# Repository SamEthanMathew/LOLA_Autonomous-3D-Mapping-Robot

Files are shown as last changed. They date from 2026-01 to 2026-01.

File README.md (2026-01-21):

# LOLA - Autonomous 3D-Mapping Robot

**Built in one week for Build18 2026**





> We built an autonomous 3D-mapping robot in one week.  
> Not a simulation. Not a demo script.  
> A real rover that drives and reconstructs the room around it.

---

## Overview

**LOLA** is a $150 mecanum-drive RC rover running on a Raspberry Pi 4 that autonomously explores and reconstructs 3D environments. The system combines LiDAR-based SLAM with RGB-only 3D reconstruction to create detailed spatial maps, all without relying on expensive depth cameras.

### Key Features

- ✅ **Real-time autonomous navigation** using LiDAR SLAM
- ✅ **3D reconstruction** from RGB video only (no depth camera needed)
- ✅ **Point-to-Line ICP (PL-ICP)** for faster and more accurate SLAM convergence
- ✅ **Cost-effective** - total build cost under $150
- ✅ **Accessible workflow** - heavy compute offloaded to Google Colab
- ✅ **Open-source** - designed for easy replication

---

## Technical Approach

### Hardware
- **Platform**: Mecanum-drive RC rover chassis
- **Compute**: Raspberry Pi 4
- **Sensor**: RPLiDAR A1/A2 for SLAM
- **Camera**: Standard RGB camera for 3D reconstruction
- **Total Cost**: ~$150

## 3D Printing

We 3D-printed several custom mounts and structural parts for LOLA using:

- **Printer**: BambuLab X1
- **Material**: PLA filament
- **Supports**: Not required (all parts were designed to print cleanly without supports)

These printed components helped with sensor mounting and securing electronics to the chassis.

## Software Architecture

```
┌─────────────────────────────────────┐
│         Raspberry Pi 4              │
│  • Motor Control                    │
│  • LiDAR SLAM (PL-ICP)              │
│  • Path Planning (RRT)              │
│  • Autonomous Navigation            │
└──────────────┬──────────────────────┘
               │
               │ Video Stream / Map Data
               ▼
┌─────────────────────────────────────┐
│    Offboard Compute (Colab/Laptop)  │
│  • CUT3R 3D Reconstruction          │
│  • Point Cloud Processing           │
└─────────────────────────────────────┘
```

### SLAM Pipeline

Our LiDAR-based SLAM implementation uses:

1. **Point-to-Line ICP (PL-ICP)** instead of traditional point-to-point ICP
   - Faster convergence
   - More accurate pose estimation
   - Better handling of sparse scan data

2. **SVD-based closed-form solve** for transformation estimation
   - Efficient computation
   - Numerically stable

3. **KD-tree for nearest-neighbor matching**
   - O(log n) query time
   - Efficient scan alignment

4. **Occupancy grid mapping** with dynamic updates
   - Real-time map visualization
   - Export to PNG for path planning

### Path Planning + Navigation

After SLAM generates an occupancy grid, LOLA plans motion through the environment using a lightweight **sampling-based path planner**.

****Pipeline:****
1. **Export occupancy grid** from SLAM (`map_exports/`)
2. Run `path_planner.py` to generate a **collision-free path** using **RRT (Rapidly-exploring Random Tree)**
3. Output waypoints + visualization:
   - `path_outputs/path_coords_*.json` (waypoint list)
   - `path_outputs/path_map_*.png` (path overlay on map)
4. `example_use_path.py` loads the JSON waypoints and sends motor commands to follow the route autonomously

****Why RRT?****
RRT is fast, simple, and works well on occupancy grids where obstacles can be irregular. It lets us generate feasible paths quickly without needing heavy compute or complex global planning libraries — perfect for a Pi-based rover.

This planning system turns our SLAM map into **actionable navigation**, enabling LOLA to autonomously explore rooms rather than just map them.

### 3D Reconstruction

We use **CUT3R** (Camera-Unified Transformer for 3D Reconstruction):
- Reconstructs 3D scenes using **only RGB video** + camera intrinsics/extrinsics
- No expensive depth cameras or structured light sensors needed
- Modified pipeline for easy iteration and team accessibility
- Runs on Google Colab for reproducibility

---

## Repository Structure

```
Build18-Contribution/
├── LiDARSensor.py              # SLAM implementation (PL-ICP, mapping, visualization)
├── path_planner.py             # RRT-based path planning on occupancy grids
├── example_use_path.py         # Example script for autonomous navigation
├── Vidto3Dmodel_Reconstruction.ipynb  # CUT3R reconstruction notebook (Colab)
├── drive/
│   └── manual_motor_control.py # Motor control interface
├── map_exports/                # Generated SLAM maps
└── path_outputs/               # Planned paths (JSON + visualization)
```

---

## Bill of Materials (BOM)

> Note: This BOM does **not** include the Raspberry Pi 4 and miscellaneous wiring/fasteners, which were not included in cost.

| # | Item | Qty | Unit Cost (USD) | Total (USD) | Product Link |
|---:|---|---:|---:|---:|---|
| 1 | Motor Driver | 1 | 10.59 | 10.59 | [L298N Motor Driver](https://www.amazon.com/dp/B0C5JCF5RS?ref=ppx_yo2ov_dt_b_fed_asin_title) |
| 2 | Robot Car Chassis | 1 | 39.21 | 39.21 | [Mecanum Robot Chassis](https://www.seeedstudio.com/Robot-car-Kit-RC-Smart-Car-Chassis-p-4226.html) |
| 3 | LiDAR Sensor | 1 | 104.94 | 104.94 | [RPLIDAR A1M8](https://a.co/d/cjdxPnk) |
| 4 | USB Camera | 1 | ~ | ~ | Used a regular pc camera |
| 5 | Pi4 Power Supply | 1 | ~ | ~ | Used a power bank |
| 6 | 9V Battery | 2 | ~ | ~ | 9V Alkaline Batteries |
|  | **Total** |  |  | **154.74** |  |

## Installation & Setup

### On Raspberry Pi 4

1. **Clone the repository**
   ```bash
   git clone https://github.com/yourusername/lola-robot.git
   cd lola-robot/Build18-Contribution
   ```

2. **Install dependencies**
   ```bash
   pip install numpy scipy pygame opencv-python rplidar-roboticia numba
   ```

3. **Connect LiDAR sensor**
   - Plug RPLiDAR into USB port
   - Verify with `ls /dev/ttyUSB*`

### For 3D Reconstruction (Colab)

1. Open `Vidto3Dmodel_Reconstruction.ipynb` in Google Colab
2. Upload your RGB video from the rover
3. Follow the notebook steps to generate 3D point clouds

---

## Usage

### 1. Run SLAM and Generate Map

```bash
python LiDARSensor.py
```

This will:
- Initialize the LiDAR sensor
- Start real-time SLAM with visualization
- Save occupancy grid maps to `map_exports/`

**Controls** (during SLAM):
- `S` - Save current map
- `R` - Reset map
- `ESC` - Exit

### 2. Plan Exploration Path

```bash
python path_planner.py map_exports/slam_map_YYYYMMDD-HHMMSS.png
```

This generates:
- `path_outputs/path_coords_*.json` - Waypoint coordinates
- `path_outputs/path_map_*.png` - Visualization of planned path

### 3. Execute Autonomous Navigation

```bash
python example_use_path.py
```

Loads the planned path and sends motor commands to follow waypoints autonomously.

### 4. 3D Reconstruction (Offboard)

1. Record RGB video while rover explores
2. Upload to Colab
3. Run `Vidto3Dmodel_Reconstruction.ipynb`
4. Download the reconstructed 3D model

---

## Results

- **SLAM Performance**: Real-time mapping at 10Hz with consistent loop closure
- **Path Planning**: RRT generates collision-free paths in <2 seconds
- **3D Reconstruction**: High-quality depth visualization showing room structure, furniture, and wall details
- **Autonomy**: Successfully navigates rooms without human intervention

---

## Team

Built with ❤️ by:
- **[Sam](https://www.linkedin.com/in/sam-mathew-1a9778254/)**
- **[Darren](https://www.linkedin.com/in/darrpinto/)**
- **[Tanay](https://www.linkedin.com/in/tanay-mishra-a86b25274/)**
- **[Jayden](https://www.linkedin.com/in/jayden-chen-3038a22a7/)**
- **[Jintong](https://www.linkedin.com/in/jintong-wang-096645289/)**

---

## Acknowledgments

Huge thanks to:
- The **Build18** organizing team
- Carnegie Mellon **ECE Department**
- All mentors who guided us throughout the sprint
- Open-source projects: CUT3R, RPLiDAR drivers, NumPy, SciPy
---

## Citation

If you use CUT3R in your work, please cite:

```bibtex
@inproceedings{cut3r,
  author    = {Qianqian Wang* and Yifei Zhang* and Aleksander Holynski and Alexei A. Efros and Angjoo Kanazawa},
  title     = {Continuous 3D Perception Model with Persistent State},
  booktitle = {CVPR},
  year      = {2025}
}
```

## Demo
Check out our 3D model generation & SLAM Pipeline demo's work: [Demo](https://github.com/SamEthanMathew/LOLA_Autonomous-3D-Mapping-Robot/commits/v1.0)

## License

This project is open-source and available under the MIT License.

---

## References

- [CUT3R: Camera-Unified Transformer for 3D Reconstruction](https://github.com/nianticlabs/cutr)
- [Point-to-Line ICP](https://ieeexplore.ieee.org/document/6906555)
- [RPLiDAR Documentation](https://www.slamtec.com/en/Lidar/A1)

---

**Built for Build18 2026** - One week. One robot. Real results.

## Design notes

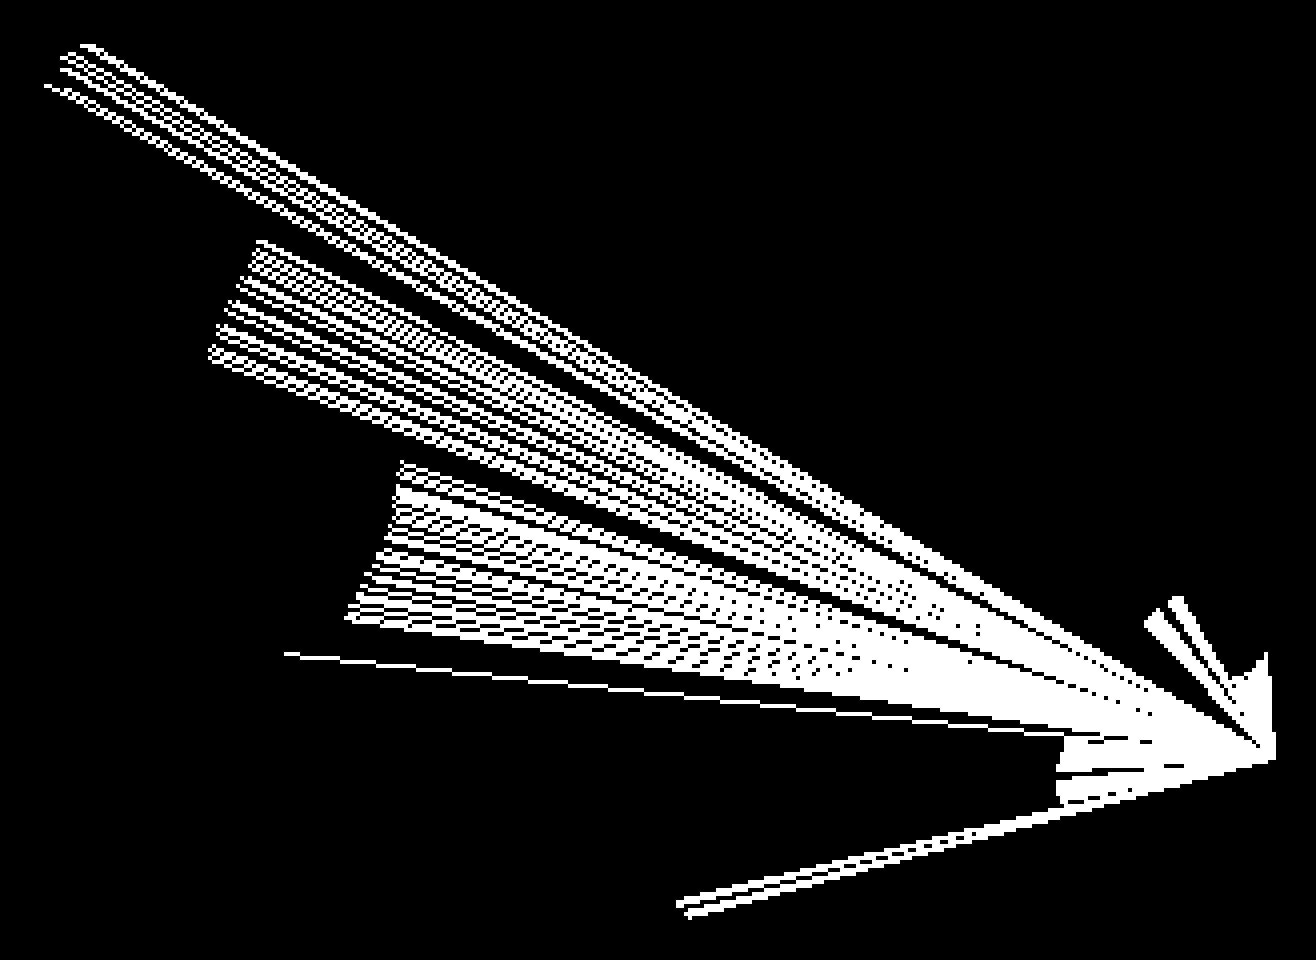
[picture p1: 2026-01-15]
map_exports/slam_map_20260114-220409.png

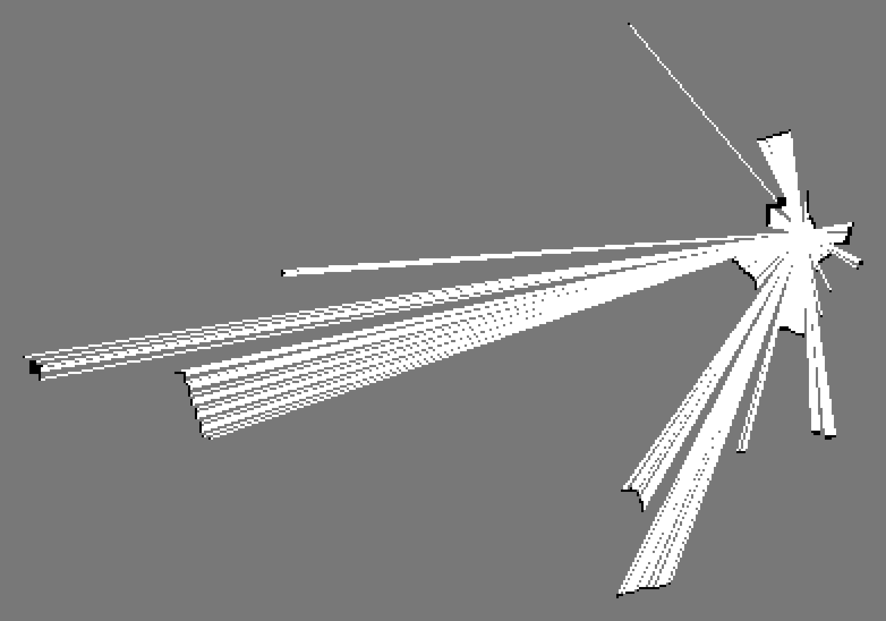
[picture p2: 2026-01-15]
map_exports/slam_map_20260114-215710.png

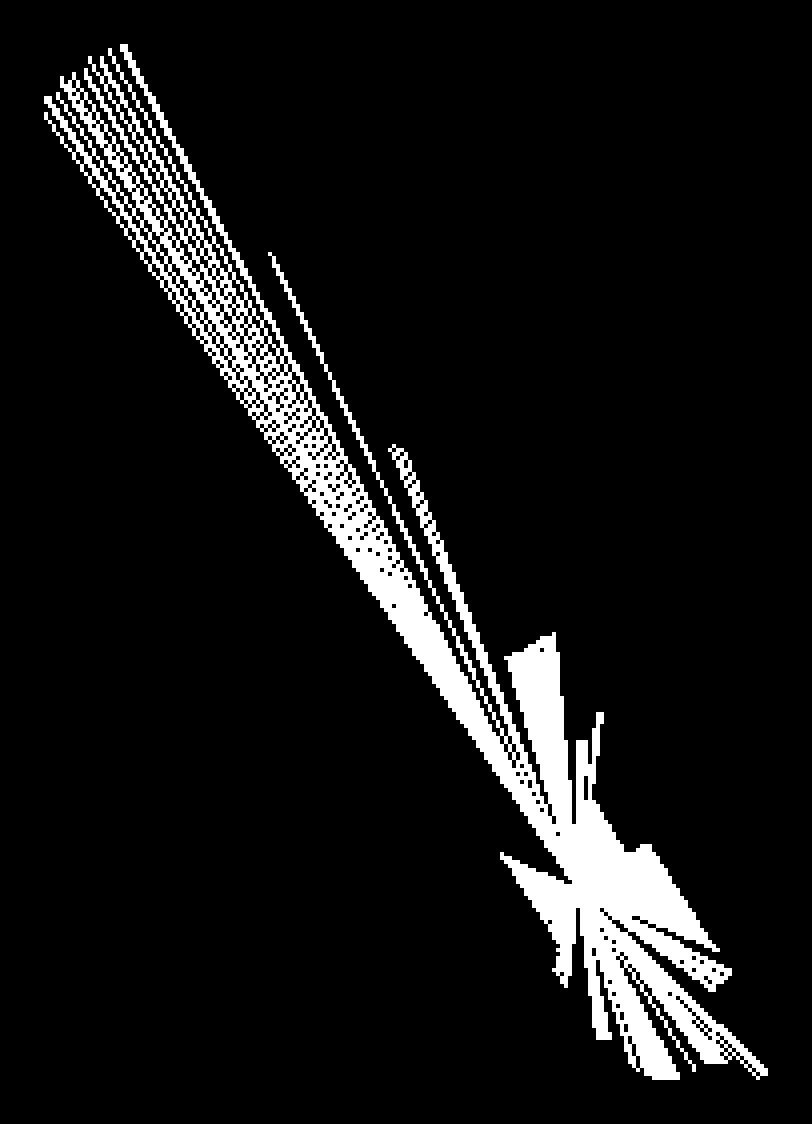
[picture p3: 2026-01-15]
map_exports/slam_map_20260114-220509.png

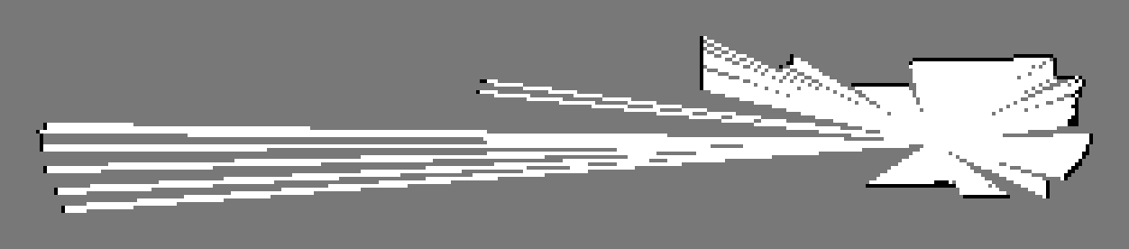
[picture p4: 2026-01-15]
map_exports/slam_map_20260114-220135.png

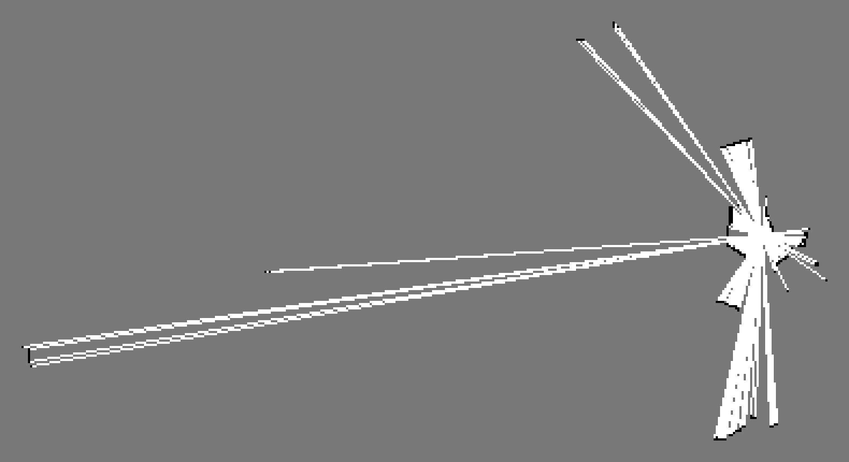
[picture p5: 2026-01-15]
map_exports/slam_map_20260114-215930.png

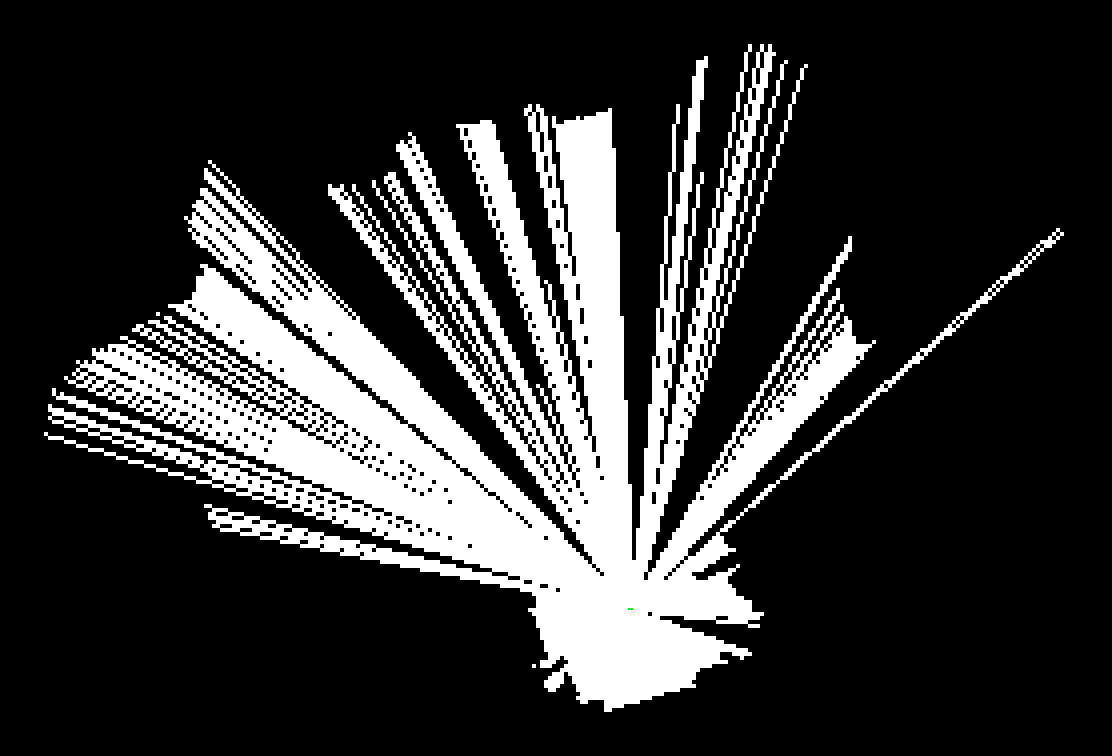
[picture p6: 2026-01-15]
map_exports/slam_map_20260114-220602.png

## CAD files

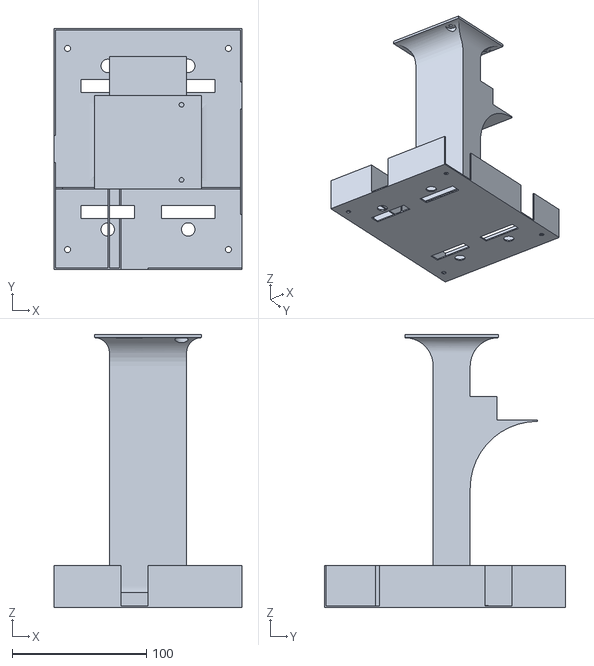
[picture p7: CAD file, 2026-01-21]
STL Files (3D prints)/chassis.STL
140.0 x 180.0 x 203.6

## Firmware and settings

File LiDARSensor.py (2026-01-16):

import threading
import json
from rplidar import RPLidar, RPLidarException
import time
import serial.tools.list_ports
import os
import pygame
import math
from collections import deque
import numpy as np
from scipy.spatial import KDTree
from scipy.ndimage import binary_closing
from scipy.spatial import KDTree
from scipy.ndimage import binary_closing
from numba import jit
import argparse

# --- SLAM Implementation ---
def best_fit_transform(A, B):
    '''
    Calculates the least-squares best-fit transform that maps corresponding points A to B in m spatial dimensions
    Input:
      A: Nxm numpy array of corresponding points
      B: Nxm numpy array of corresponding points
    Returns:
      T: (m+1)x(m+1) homogeneous transformation matrix
      R: mxm rotation matrix
      t: mx1 translation vector
    '''

    assert A.shape == B.shape

    # get number of dimensions
    m = A.shape[1]

    # translate points to their centroids
    centroid_A = np.mean(A, axis=0)
    centroid_B = np.mean(B, axis=0)
    AA = A - centroid_A
    BB = B - centroid_B

    # rotation matrix
    H = np.dot(AA.T, BB)
    U, S, Vt = np.linalg.svd(H)
    R = np.dot(Vt.T, U.T)

    # special reflection case
    if np.linalg.det(R) < 0:
       Vt[m-1,:] *= -1
       R = np.dot(Vt.T, U.T)

    # translation
    t = centroid_B.T - np.dot(R, centroid_A.T)

    # homogeneous transformation
    T = np.identity(m+1)
    T[:m, :m] = R
    T[:m, m] = t

    return T, R, t

@jit(nopython=True)
def bresenham_line(x0, y0, x1, y1):
    """
    Bresenham's Line Algorithm
    Returns a list of (x, y) tuples from (x0, y0) to (x1, y1)
    """
    points = []
    dx = abs(x1 - x0)
    dy = abs(y1 - y0)
    x, y = x0, y0
    sx = -1 if x0 > x1 else 1
    sy = -1 if y0 > y1 else 1
    
    if dx > dy:
        err = dx / 2.0
        while x != x1:
            points.append((x, y))
            err -= dy
            if err < 0:
                y += sy
                err += dx
            x += sx
    else:
        err = dy / 2.0
        while y != y1:
            points.append((x, y))
            err -= dx
            if err < 0:
                x += sx
                err += dy
            y += sy
    points.append((x, y))
    return points

def compute_normals(points, k=5):
    """
    Estimate normals for a 2D point cloud using k-nearest neighbors and PCA.
    Returns: N x 2 array of normal vectors.
    """
    if len(points) < k:
        return np.zeros((len(points), 2)) # Fallback
        
    tree = KDTree(points)
    normals = []
    
    # Query k neighbors for all points at once
    # k+1 because the point itself is included
    dists, indices = tree.query(points, k=k+1)
    
    for i, idxs in enumerate(indices):
        neighbors = points[idxs]
        # PCA
        mean = np.mean(neighbors, axis=0)
        centered = neighbors - mean
        cov = np.dot(centered.T, centered)
        values, vectors = np.linalg.eig(cov)
        
        # Normal is eigenvector corresponding to smallest eigenvalue
        min_idx = np.argmin(values)
        normal = vectors[:, min_idx]
        normals.append(normal)
        
    return np.array(normals)

def icp(A, B, init_pose=(0,0,0), max_iterations=20, tolerance=0.001):
    """
    The Iterative Closest Point method: aligns source A to target B
    Uses Point-to-Line metric via projected targets.
    """
    # Initial transform
    src = np.copy(A)
    
    # Pre-compute Target Info
    # 1. Build KD-Tree for B (Efficiency)
    target_tree = KDTree(B)
    
    # 2. Compute Normals for B (Point-to-Line)
    # Only if B has enough points
    use_plicp = len(B) > 10
    if use_plicp:
        B_normals = compute_normals(B, k=6)
    
    # Apply initial estimate
    theta = init_pose[2]
    c, s = math.cos(theta), math.sin(theta)
    R_init = np.array([[c, -s], [s, c]])
    src = np.dot(src, R_init.T)
    src += init_pose[:2]
    
    prev_error = 0
    total_T = np.identity(3)
    
    # Handle initial offset in matrix form
    T_init = np.identity(3)
    T_init[:2, :2] = R_init
    T_init[:2, 2] = init_pose[:2]
    total_T = np.dot(T_init, total_T)

    for i in range(max_iterations):
        # 1. Find correspondence
        # Query tree for all src points
        distances, indices = target_tree.query(src)
        
        target_points = B[indices]
        
        # 2. Optimize
        if use_plicp:
            # Point-to-Line Improvement:
            # Project src points onto the plane defined by (target_point, normal)
            # q_proj = p - dot(p - q, n) * n
            # But wait, we want to align 'src' to 'target line'.
            # We treat 'q_proj' as the point 'src' should try to reach to satisfy the planar constraint.
            
            normals = B_normals[indices]
            
            # Vector from point in B to point in A
            diff = src - target_points
            
            # Project this vector onto the normal
            # dot product row-wise
            dist_along_normal = np.sum(diff * normals, axis=1)
            
            # The target point on the "line" is src shifted back along the normal
            # dest = src - dist * normal
            # This works effectively as allowing sliding along the wall
            target_points_proj = src - (normals * dist_along_normal[:, np.newaxis])
            
            # Use these projected points as targets for standard SVD solver
            T, _, _ = best_fit_transform(src, target_points_proj)
        else:
             # Standard Point-to-Point
             T, _, _ = best_fit_transform(src, target_points)

        # 3. Update
        src_h = np.ones((src.shape[0], 3))
        src_h[:,:2] = src
        src_h = np.dot(T, src_h.T).T
        src = src_h[:,:2]

        total_T = np.dot(T, total_T)

        # Check error (Mean Distance)
        mean_error = np.mean(distances)
        if np.abs(prev_error - mean_error) < tolerance:
            break
        prev_error = mean_error

    return total_T, distances

class SimpleSLAM:
    def __init__(self):
        # PROBABILISTIC GRID MAP
        # Key: (int_x, int_y) tuple representing 30mm grid cells
        # Value: [sum_x, sum_y, count]
        self.global_grid = {} 
        self.GRID_RESOLUTION = 30 # mm
        
        self.pose = np.array([0.0, 0.0, 0.0]) # x, y, theta
        self.path = [] # History of poses
        
        self.scan_buffer = [] # Buffer to accumulate scans before SLAM update
        self.SCAN_BUFFER_SIZE = 4 # How many scans to merge (robustness)
        self.prev_dense_scan = None
        
    def process_scan(self, scan_points):
        """
        Accumulates scans to create a dense 'Keyframe'.
        Runs ICP only when buffer is full.
        """
        # 1. Convert to Cartesian (Robot Frame)
        current_scan = []
        for p in scan_points:
            if p.distance > 0:
                rad = math.radians(p.angle)
                x = p.distance * math.cos(rad)
                y = p.distance * math.sin(rad)
                current_scan.append([x, y])
        
        # Add to buffer
        if len(current_scan) > 10:
             self.scan_buffer.extend(current_scan)
             
        # Only process if buffer is full (Signal Integration)
        # We assume robot moves slowly enough that 4 scans (~0.5s) is "static" enough
        # or that the blur is acceptable for specific density.
        current_rev = scan_points[0].revolution if scan_points else 0
        
        # Check if we have enough data (using a simple counter or checking length)
        # Since process_scan is called once per revolution roughly
        # We need a counter in the class, or just check list length logic
        # But process_scan is called per frame? No, per revolution based on main loop.
        # So we just count calls?
        # Let's use the length of the buffer as a proxy? No, scans vary.
        # Let's add a counter.
        
        if not hasattr(self, 'buffer_count'):
             self.buffer_count = 0
        self.buffer_count += 1
        
        if self.buffer_count < self.SCAN_BUFFER_SIZE:
             return
             
        # --- PROCESS KEYFRAME ---
        self.buffer_count = 0
        if not self.scan_buffer:
             return
             
        dense_scan = np.array(self.scan_buffer)
        self.scan_buffer = [] # Clear for next batch
        
        # DOWNSAMPLE if too huge (ICP speed)
        # 4 scans * 200 pts = 800 pts. limit to 400 for speed?
        if len(dense_scan) > 400:
             indices = np.linspace(0, len(dense_scan)-1, 400, dtype=int)
             dense_scan_small = dense_scan[indices]
        else:
             dense_scan_small = dense_scan

        # 2. Estimate Motion (ICP)
        d_pose = np.identity(3)
        moved = False
        
        if self.prev_dense_scan is not None:
             try:
                 # Align current dense scan to previous dense scan
                 T, distances = icp(dense_scan_small, self.prev_dense_scan)
                 d_pose = T
                 
                 # Check Motion Thresholds (Keyframe Logic)
                 # prevents drift when static
                 dx = d_pose[0, 2]
                 dy = d_pose[1, 2]
                 dtheta = math.atan2(d_pose[1, 0], d_pose[0, 0])
                 
                 dist_moved = math.sqrt(dx*dx + dy*dy)
                 rot_moved = abs(math.degrees(dtheta))
                 
                 if dist_moved > 20 or rot_moved > 2.0: # 20mm or 2 degrees
                      moved = True
                 else:
                      # If motion is tiny, ignore it to prevent drift?
                      # Or accumulate it? safer to ignore for "rock solid" static map
                      d_pose = np.identity(3) # Force zero
                      # But we might still want to add points to map if new area seen?
                      # No, if we didn't move, we see same thing.
                      pass

             except Exception as e:
                 print(f"ICP Error: {e}")
                 pass
        else:
             moved = True # First frame always updates
        
        # Extract refined delta
        dx = d_pose[0, 2]
        dy = d_pose[1, 2]
        dtheta = math.atan2(d_pose[1, 0], d_pose[0, 0])
        
        # 3. Update Global Pose
        gx = dx * math.cos(self.pose[2]) - dy * math.sin(self.pose[2])
        gy = dx * math.sin(self.pose[2]) + dy * math.cos(self.pose[2])
        
        self.pose[0] += gx
        self.pose[1] += gy
        self.pose[2] += dtheta
        
        # 4. Update Map & Reference
        # If we moved (or it's the first frame), update the map
        if moved or self.prev_dense_scan is None:
             c, s = math.cos(self.pose[2]), math.sin(self.pose[2])
             R_global = np.array([[c, -s], [s, c]])
             
             # Transform dense scan to global
             global_points = np.dot(dense_scan, R_global.T) + self.pose[:2]
             
             # PROBABILISTIC UPDATE (RAYCASTING)
             # Update cells along the ray to be FREE
             # Update end point to be OCCUPIED
             
             # Convert robot pose to grid coords
             rob_ix = int(round(self.pose[0] / self.GRID_RESOLUTION))
             rob_iy = int(round(self.pose[1] / self.GRID_RESOLUTION))
             
             for p in global_points:
                 gx, gy = p[0], p[1]
                 ix = int(round(gx / self.GRID_RESOLUTION))
                 iy = int(round(gy / self.GRID_RESOLUTION))
                 
                 # Raycast from robot to hit point
                 # 'bresenham_line' returns integers
                 cells = bresenham_line(rob_ix, rob_iy, ix, iy)
                 
                 # Mark free space (all except last one)
                 for i in range(len(cells) - 1):
                     cx, cy = cells[i]
                     key = (cx, cy)
                     if key in self.global_grid:
                         # DECREASE occupancy
                         # We use a float for probability-like behavior:
                         # 0.0 = Free, >1.0 = Occupied
                         self.global_grid[key][2] = max(0.1, self.global_grid[key][2] - 0.5) 
                     else:
                         # Register as Free Space (Seen, but empty)
                         # We store [cx, cy, count]
                         # Using 0.01 to indicate "we saw it, but it's empty"
                         # We need the real coordinates for the key roughly
                         self.global_grid[key] = [cx * self.GRID_RESOLUTION, cy * self.GRID_RESOLUTION, 0.1]
                 
                 # Mark occupied (last point)
                 key = (ix, iy)
                 if key in self.global_grid:
                     cell = self.global_grid[key]
                     # Fuse
                     if cell[2] < 50:
                         cell[0] += gx
                         cell[1] += gy
                         cell[2] += 1.0 # Add 1 for hit
                 else:
                     self.global_grid[key] = [gx, gy, 1.0]
                          
             self.prev_dense_scan = dense_scan_small # Update reference
             self.path.append(self.pose.copy())
             
    def get_map_points(self):
        """Reconstruct list of points [x,y] from the grid (Mean values)"""
        points = []
        for key, val in self.global_grid.items():
            # if val[2] > 1: # Optional filter: only confirmed points?
            points.append([val[0]/val[2], val[1]/val[2]])
        return points

    def get_pose(self):
        """Returns (x, y, theta_degrees)"""
        return self.pose[0], self.pose[1], math.degrees(self.pose[2])

    # GET TURN ANGLE
    def calculate_exploration_vector(self, cartesian_points):
        """
        Returns the angle (degrees) of the 'deepest' sector (most open space).
        Input: numpy array or list of [x, y] points (in robot local frame)
        """
        if len(cartesian_points) == 0:
            return None
            
        # Analyze in 10-degree sectors
        SECTOR_SIZE = 10
        num_sectors = 360 // SECTOR_SIZE
        sector_sums = [0.0] * num_sectors
        sector_counts = [0] * num_sectors
        
        # Convert Cart to Polar
        for p in cartesian_points:
            x, y = p[0], p[1]
            dist = math.sqrt(x*x + y*y)
            if dist > 0:
                angle_rad = math.atan2(y, x)
                angle_deg = math.degrees(angle_rad) % 360
                
                idx = int(angle_deg // SECTOR_SIZE)
                
                if 0 <= idx < num_sectors:
                    sector_sums[idx] += dist
                    sector_counts[idx] += 1
                    
        best_idx = -1
        max_avg = -1.0
        
        for i in range(num_sectors):
            if sector_counts[i] > 5: # Threshold
                avg = sector_sums[i] / sector_counts[i]
                if avg > max_avg:
                    max_avg = avg
                    best_idx = i
                    
        if best_idx != -1:
            # Return center angle
            # We want -180 to 180 range usually? 
            # Logic above uses 0-360.
            angle = best_idx * SECTOR_SIZE + (SECTOR_SIZE / 2)
            if angle > 180: angle -= 360
            return angle
        return None

    def get_turn_command(self):
        """
        Calculates the best direction to move into open space.
        Returns:
            angle_deg (float): The relative angle to turn (negative=right, positive=left).
                               Returns None if no map data.
        """
        map_pts = self.get_map_points()
        if len(map_pts) < 10:
            return None
            
        recent_map = np.array(map_pts)
        
        # Transform Global -> Local
        rob_x, rob_y, rob_theta = self.pose
        c, s = math.cos(rob_theta), math.sin(rob_theta)
        R_inv = np.array([[c, s], [-s, c]])
        
        pts_centered = recent_map - np.array([rob_x, rob_y])
        local_map_pts = np.dot(pts_centered, R_inv.T)
        
        target_angle_local = self.calculate_exploration_vector(local_map_pts)
        return target_angle_local

def normalize_angle(angle_deg):
    """Normalize angle to [-180, 180]"""
    while angle_deg > 180:
        angle_deg -= 360
    while angle_deg <= -180:
        angle_deg += 360
    return angle_deg



slam_system = SimpleSLAM()

# 46 degrees
# 133 degrees
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

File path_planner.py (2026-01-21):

#!/usr/bin/env python3
"""
SLAM Map Path Planning System
Generates exploration paths using RRT algorithm on SLAM-generated occupancy grid maps.
"""

import numpy as np
import cv2
import json
import argparse
import time
from pathlib import Path
from datetime import datetime
from scipy.spatial import KDTree
from typing import List, Tuple, Optional, Dict
import random
import math


# ============================================================================
# CONSTANTS
# ============================================================================

# SLAM export parameters (from LiDARSensor.py)
GRID_RESOLUTION_MM = 30  # mm per cell (line 217 in LiDARSensor.py)
EXPORT_SCALE_PX_PER_CELL = 4  # pixels per cell (line 719 in LiDARSensor.py)
MM_PER_PIXEL = GRID_RESOLUTION_MM / EXPORT_SCALE_PX_PER_CELL  # 7.5 mm/pixel

# Path planning parameters
OBSTACLE_PADDING_PX = 5  # Safety margin around obstacles
RRT_STEP_SIZE_PX = 30  # Maximum extension distance per iteration
RRT_MAX_ITERATIONS = 5000  # Maximum iterations for RRT
GOAL_BIAS_PROBABILITY = 0.1  # Probability of sampling toward goal


# ============================================================================
# MAP PROCESSING MODULE
# ============================================================================

class MapProcessor:
    """Handles map loading and preprocessing."""
    
    def __init__(self, image_path: str):
        """
        Load and process a SLAM map image.
        
        Args:
            image_path: Path to the PNG map image
        """
        self.image_path = Path(image_path)
        if not self.image_path.exists():
            raise FileNotFoundError(f"Map image not found: {image_path}")
        
        # Load image
        self.original_image = cv2.imread(str(self.image_path))
        if self.original_image is None:
            raise ValueError(f"Failed to load image: {image_path}")
        
        # Convert to grayscale
        self.gray_image = cv2.cvtColor(self.original_image, cv2.COLOR_BGR2GRAY)
        self.height, self.width = self.gray_image.shape
        
        # Extract free space mask
        self.free_space_mask = self._extract_free_space()
        
        # Create padded obstacle map for safety
        self.safe_mask = self._create_safe_mask()
        
        print(f"Loaded map: {self.width}x{self.height} pixels")
        print(f"Free space pixels: {np.sum(self.free_space_mask)}")
        print(f"Safe space pixels: {np.sum(self.safe_mask)}")
    
    def _extract_free_space(self) -> np.ndarray:
        """
        Extract free space from the map.
        White pixels (255) = free space
        Black pixels (0) = obstacles or unknown
        
        Returns:
            Binary mask where True = navigable space
        """
        # Threshold: consider pixels > 200 as free space
        _, binary_mask = cv2.threshold(self.gray_image, 200, 255, cv2.THRESH_BINARY)
        return binary_mask == 255
    
    def _create_safe_mask(self) -> np.ndarray:
        """
        Create a safety-padded version of free space.
        Erodes free space to add safety margin around obstacles.
        
        Returns:
            Binary mask with safety padding applied
        """
        # Convert free space to uint8 for morphological operations
        free_uint8 = (self.free_space_mask * 255).astype(np.uint8)
        
        # Erode to create safety margin (padding around obstacles)
        kernel = np.ones((OBSTACLE_PADDING_PX, OBSTACLE_PADDING_PX), np.uint8)
        eroded = cv2.erode(free_uint8, kernel, iterations=1)
        
        return eroded == 255
    
    def is_point_free(self, x: int, y: int, use_safe_mask: bool = True) -> bool:
        """
        Check if a point is in free space.
        
        Args:
            x, y: Pixel coordinates
            use_safe_mask: If True, use safety-padded mask
            
        Returns:
            True if point is navigable
        """
        if x < 0 or x >= self.width or y < 0 or y >= self.height:
            return False
        
        mask = self.safe_mask if use_safe_mask else self.free_space_mask
        return mask[y, x]
    
    def is_line_free(self, x1: int, y1: int, x2: int, y2: int, 
                     use_safe_mask: bool = True) -> bool:
        """
        Check if a line segment is entirely in free space.
        
        Args:
            x1, y1: Start point
            x2, y2: End point
            use_safe_mask: If True, use safety-padded mask
            
        Returns:
            True if entire line is navigable
        """
        # Use Bresenham's line algorithm to sample points along line
        num_samples = int(np.hypot(x2 - x1, y2 - y1)) + 1
        xs = np.linspace(x1, x2, num_samples, dtype=int)
        ys = np.linspace(y1, y2, num_samples, dtype=int)
        
        for x, y in zip(xs, ys):
            if not self.is_point_free(x, y, use_safe_mask):
                return False
        
        return True
    
    def get_random_free_point(self, use_safe_mask: bool = True) -> Optional[Tuple[int, int]]:
        """
        Get a random point in free space.
        
        Args:
            use_safe_mask: If True, use safety-padded mask
            
        Returns:
            (x, y) tuple or None if no free space found
        """
        mask = self.safe_mask if use_safe_mask else self.free_space_mask
        free_points = np.argwhere(mask)
        
        if len(free_points) == 0:
            return None
        
        # Random selection
        idx = random.randint(0, len(free_points) - 1)
        y, x = free_points[idx]
        return (x, y)
    
    def get_center_free_point(self, use_safe_mask: bool = True) -> Optional[Tuple[int, int]]:
        """
        Get a free point near the center of the largest connected component.
        
        Args:
            use_safe_mask: If True, use safety-padded mask
            
        Returns:
            (x, y) tuple or None if no free space found
        """
        mask = self.safe_mask if use_safe_mask else self.free_space_mask
        mask_uint8 = (mask * 255).astype(np.uint8)
        
        # Find connected components
        num_labels, labels, stats, centroids = cv2.connectedComponentsWithStats(
            mask_uint8, connectivity=8
        )
        
        if num_labels <= 1:  # Only background
            return None
        
        # Find largest component (skip 0 which is background)
        areas = stats[1:, cv2.CC_STAT_AREA]
        largest_idx = np.argmax(areas) + 1
        
        # Get centroid of largest component
        cx, cy = centroids[largest_idx]
        x, y = int(cx), int(cy)
        
        # Verify it's actually free
        if self.is_point_free(x, y, use_safe_mask):
            return (x, y)
        
        # If centroid is not free, find nearest free point
        component_mask = labels == largest_idx
        free_points = np.argwhere(component_mask)
        
        if len(free_points) == 0:
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

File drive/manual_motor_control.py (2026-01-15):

import curses
import sys
from gpiozero import Motor, PWMOutputDevice


class Vehicle:
    def __init__(self):
        self.FL_motor = Motor(forward=27, backward=22)
        self.FL_pwm = PWMOutputDevice(17)
        self.FL_pwm.value = 0

        self.FR_motor = Motor(forward=24, backward=23)
        self.FR_pwm = PWMOutputDevice(25)
        self.FR_pwm.value = 0

        self.BL_motor = Motor(forward=6, backward=5)
        self.BL_pwm = PWMOutputDevice(13)
        self.BL_pwm.value = 0

        self.BR_motor = Motor(forward=16, backward=26)
        self.BR_pwm = PWMOutputDevice(12)
        self.BR_pwm.value = 0
        

    def forward(self):
        self.FL_motor.forward()
        self.FR_motor.forward()
        self.BL_motor.forward()
        self.BR_motor.forward()

        self.FL_pwm.value = 0.5
        self.FR_pwm.value = 0.5
        self.BL_pwm.value = 0.5
        self.BR_pwm.value = 0.5

    def backward(self):
        self.FL_motor.backward()
        self.FR_motor.backward()
        self.BL_motor.backward()
        self.BR_motor.backward()

        self.FL_pwm.value = 0.5
        self.FR_pwm.value = 0.5
        self.BL_pwm.value = 0.5
        self.BR_pwm.value = 0.5

    def slide_left(self):
        self.FL_motor.backward()
        self.FR_motor.forward()
        self.BL_motor.forward()
        self.BR_motor.backward()

        self.FL_pwm.value = 0.5
        self.FR_pwm.value = 0.5
        self.BL_pwm.value = 0.5
        self.BR_pwm.value = 0.5

    def slide_right(self):
        self.FL_motor.forward()
        self.FR_motor.backward()
        self.BL_motor.backward()
        self.BR_motor.forward()

        self.FL_pwm.value = 0.5
        self.FR_pwm.value = 0.5
        self.BL_pwm.value = 0.5
        self.BR_pwm.value = 0.5

    def turn_left(self):
        self.FL_motor.backward()
        self.FR_motor.forward()
        self.BL_motor.backward()
        self.BR_motor.forward()

        self.FL_pwm.value = 0.5
        self.FR_pwm.value = 0.5
        self.BL_pwm.value = 0.5
        self.BR_pwm.value = 0.5

    def turn_right(self):
        self.FL_motor.forward()
        self.FR_motor.backward()
        self.BL_motor.forward()
        self.BR_motor.backward()

        self.FL_pwm.value = 0.5
        self.FR_pwm.value = 0.5
        self.BL_pwm.value = 0.5
        self.BR_pwm.value = 0.5

    def map_key_to_command(self, key):
        map = {
            curses.KEY_UP: self.forward,
            curses.KEY_DOWN: self.backward,
            curses.KEY_LEFT: self.turn_left,
            curses.KEY_RIGHT: self.turn_right,
            ord('w'): self.forward,
            ord('s'): self.backward,
            ord('a'): self.slide_left,
            ord('d'): self.slide_right,
            ord('q'): self.turn_left,
            ord('e'): self.turn_right
        }
        return map[key]

    def control(self, key):
        return self.map_key_to_command(key)


rpi_vehicle = Vehicle()


def main(window):
    next_key = None

    while True:
        curses.halfdelay(1)
        if next_key is None:
            key = window.getch()
            print(key)
        else:
            key = next_key
            next_key = None
        if key == 99:
            sys.exit()
        if key != -1:
            # KEY PRESSED
            curses.halfdelay(1)
            action = rpi_vehicle.control(key)
            if action:
                action()
            next_key = key
            while next_key == key:
                next_key = window.getch()
            # KEY RELEASED
            rpi_vehicle.FL_motor.stop()
            rpi_vehicle.FR_motor.stop()
            rpi_vehicle.BL_motor.stop()
            rpi_vehicle.BR_motor.stop()


curses.wrapper(main)

# thank you mcdominik

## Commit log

2026-01-15 lidar map export + ui finished
2026-01-15 Implement manual motor control for vehicle
2026-01-16 lidar improvements
2026-01-21 added 3d model
    [chassis.STL]

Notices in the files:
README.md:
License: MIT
